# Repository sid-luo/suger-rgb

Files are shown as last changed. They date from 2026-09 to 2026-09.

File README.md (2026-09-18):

<p align="center">
  Suger RGB
</p>

<h1 align="center">Suger RGB</h1>

## ⚠️ DO NOT USE ESP32-C3 SUPER MINI — USE ESP32-C3 PRO MINI

> [!WARNING]
> **Do not buy or use an ESP32-C3 Super Mini (SuperMini) for this project.** These boards may have unreliable Wi-Fi, an undiscoverable setup hotspot, or failed Wi-Fi setup. A successful firmware flash does not guarantee working Wi-Fi.
>
> These issues occurred during this project's testing and were resolved by switching to an **ESP32-C3 Pro Mini**. **Choose the ESP32-C3 Pro Mini for this project.**

<p align="center">Turn Nightscout glucose and trend data into light you can understand at a glance.</p>

> [!TIP]
> ### ☁️ No Nightscout yet? Start in the cloud. Bring it to light.
>
> Try my other open-source project, [Nightscout for Cloudflare](https://github.com/sid-luo/nightscout-for-cloudflare): powered by Cloudflare, **ready to deploy in minutes**, and **completely free (no credit card required)**. **All your data stays under your control**, with no need to buy a server or configure MongoDB. Once it is set up, connect Suger RGB to bring your glucose levels and trends into the light around you.
>
> **[Explore the project →](https://github.com/sid-luo/nightscout-for-cloudflare)** · **[Deploy in your browser →](https://nscf.sidluo.com)**

<p align="center">
  <strong>English</strong> · <a href="README.zh-CN.md">简体中文</a>
</p>

<p align="center">
  <a href="https://rgb.sidluo.com/installer/"><strong>Web installer</strong></a>
  · <a href="https://rgb.sidluo.com/demo/"><strong>Effect demo</strong></a>
  · <a href="docs/GUIDE.en.md"><strong>Full guide</strong></a>
</p>

Suger RGB is an open-source glucose indicator built with an ESP32-C3 Pro Mini, WS2812B LEDs, and Nightscout. It reads the latest glucose value once per minute, uses color for the glucose range, and changes the light effect with the glucose trend.

This project aims to provide a low-cost way to help observe glucose trends. Search for `esp32-c3-mini-pro` and `ws2812b` on AliExpress, and you'll find plenty of affordable options. My skills are limited, and I don't currently have a 3D-printable model of my own. I only have one downloaded from [here](https://makerworld.com/zh/models/2008412-case-for-esp32-c3-pro-mini-esp32-c3fh4#profileId-2163305), which just about works for an LED strip. I'd appreciate support from more experienced makers.

When using a CGM, I often receive an alert only after my glucose has already gone high or low. After years of managing my glucose, I believe that seeing glucose trends “passively” is a very important part of the process. By the time I receive an alert from the CGM app, it may already be too late. Noticing changes in the light out of the corner of my eye can help me intervene earlier and try to avoid high or low glucose.

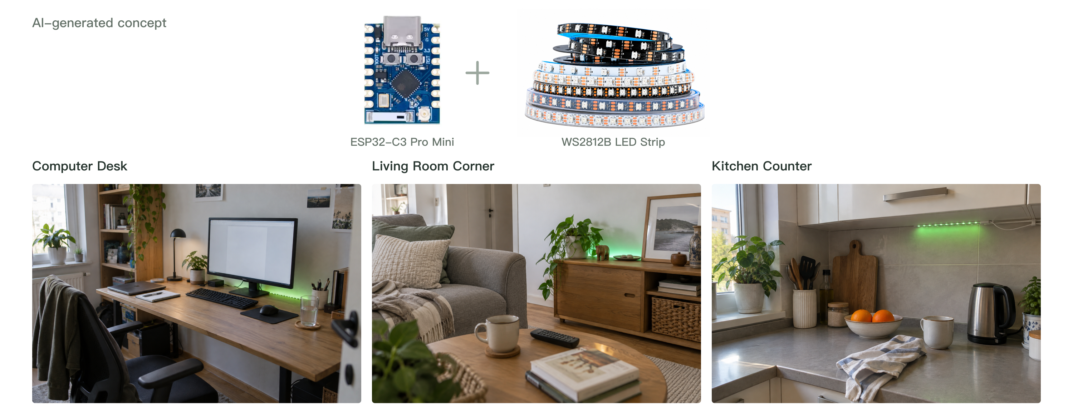
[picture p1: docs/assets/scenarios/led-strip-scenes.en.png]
LED strip scenes: computer desk, living room, and kitchen


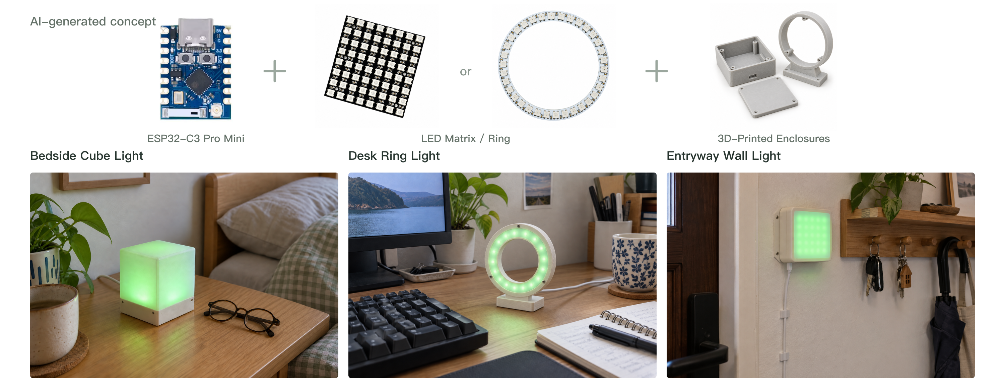
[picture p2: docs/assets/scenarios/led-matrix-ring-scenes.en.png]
LED matrix / ring and 3D-printed enclosure concepts


> [!IMPORTANT]
> Suger RGB is an open-source, community-based DIY project. It is not supported by any company and is not officially approved or regulated for diabetes therapy. You are responsible for building and running the device and use it at your own risk.

## What it shows

| mmol/L | mg/dL | Color |
| ---: | ---: | --- |
| `<3.5` | `<63` | Purple |
| `3.5–<4.4` | `63–79` | Blue |
| `4.4–<8.5` | `80–152` | Green |
| `8.5–<10` | `153–179` | Orange |
| `≥10` | `≥180` | Red |

The light effect changes with the Nightscout glucose trend. Open the [effect demo](https://rgb.sidluo.com/demo/) to see each glucose and arrow combination directly.

- A white breathing light appears when no valid new reading has arrived for 10 minutes
- The phone setup page supports Chinese, English, and live effect preview on the LEDs
- Works with 1–128 WS2812B pixels in a strip, ring, or panel

## What you need

### ⚠️ REMINDER: DO NOT BUY ESP32-C3 SUPER MINI

**Buy an ESP32-C3 Pro Mini. Super Mini boards may have Wi-Fi problems; do not use them for this project.**

| Part | Requirement |
| --- | --- |
| Controller | ESP32-C3 Pro Mini |
| LEDs | WS2812B strip, ring, or panel with 1–128 pixels |
| USB | A USB data cable and 5 V / 2 A power source |
| Network | 2.4 GHz Wi-Fi and an anonymously readable Nightscout site |

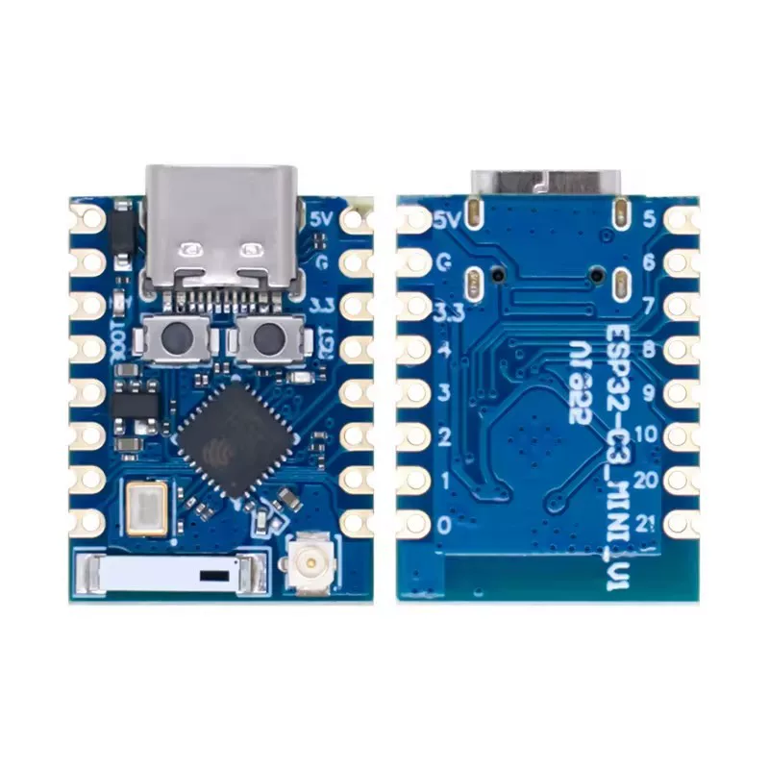
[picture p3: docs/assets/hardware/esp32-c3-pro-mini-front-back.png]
ESP32-C3 Pro Mini — front and back


Original board photo: front on the left, back on the right.

**Optional board enclosure**: [Original STL (body + lid)](docs/models/esp32-c3-pro-mini/Case_ESP32-C3_PRO_MINI_V01.stl) · [Body only](docs/models/esp32-c3-pro-mini/Case_ESP32-C3_PRO_MINI_V01_Body.stl) · [Lid only](docs/models/esp32-c3-pro-mini/Case_ESP32-C3_PRO_MINI_V01_Lid.stl). If your printing service does not accept the combined file, upload the body and lid separately. See the [model notes](docs/models/esp32-c3-pro-mini/README.en.md) for the designer, source, and license.

## Wiring

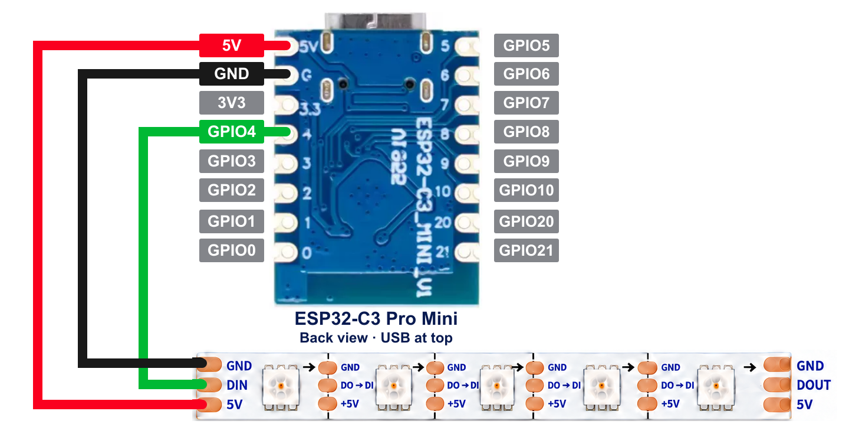
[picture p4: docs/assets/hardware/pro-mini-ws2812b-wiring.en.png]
ESP32-C3 Pro Mini GPIO4 to WS2812B DIN wiring


The wiring diagram shows the **back of the board with USB at the top**. Connect **5V → 5V, GND → GND, GPIO4 → DIN**. Follow the labels on your actual strip; pad order can vary.

```text
ESP32-C3 Pro Mini          WS2812B

5V    -------------------- 5V
GND   -------------------- GND
GPIO4 -------------------> DIN
```

Connect the data wire to `DIN`, not `DOUT`.

Board wiring close-up

## Get started

1. Connect the three wires above, then connect the ESP32-C3 Pro Mini over USB.
2. Open the [web installer](https://rgb.sidluo.com/installer/) in desktop Chrome or Edge and install the firmware.
3. Join the open `Suger-RGB-XXXX` Wi-Fi network on your phone.
4. Enter home Wi-Fi, the Nightscout address, and the LED count, then validate and save.
5. After restarting, the device reads Nightscout and displays the light automatically.

**Phone setup page**

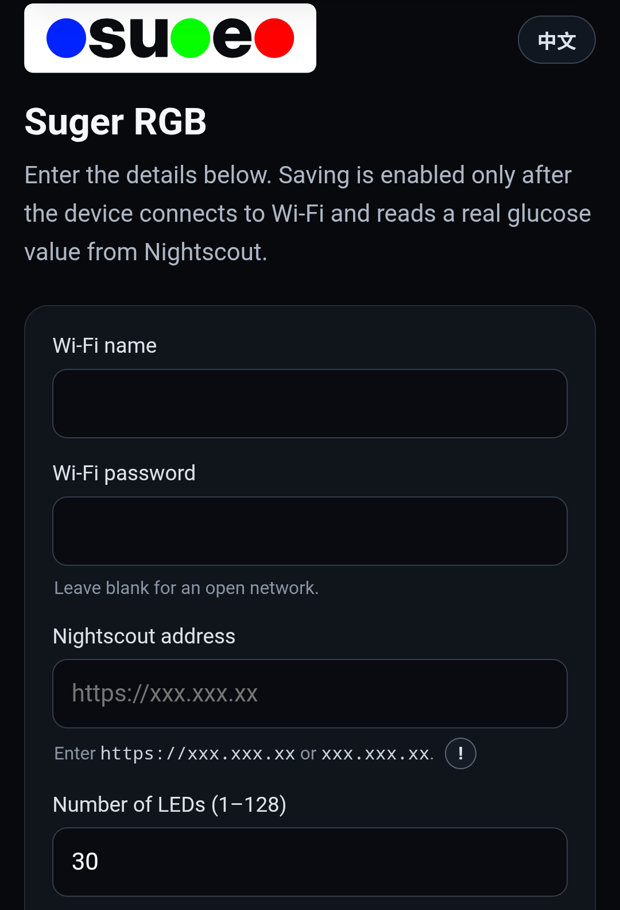
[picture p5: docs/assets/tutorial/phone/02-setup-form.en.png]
English setup page on a phone


To change the setup later, hold the board's BOOT button for about five seconds. See the [full user guide](docs/GUIDE.en.md) for every step and troubleshooting.

## Documentation

- [Full user guide](docs/GUIDE.en.md)
- [Interactive effect demo](https://rgb.sidluo.com/demo/)

## License and credits

Suger RGB is released under the [GNU GPL v3.0 or later](LICENSE). Some effects are adapted from MIT-licensed [WLED v0.14.4](https://github.com/wled/WLED/tree/v0.14.4). See [THIRD_PARTY_NOTICES.md](THIRD_PARTY_NOTICES.md) for complete source and copyright notices.

The board enclosure model is by Mattia Carli. The original and split STL files are separately licensed under [CC BY-NC-SA 4.0](https://creativecommons.org/licenses/by-nc-sa/4.0/).

Thanks to the [Nightscout](https://nightscout.github.io/) community, the WLED project, and every open-source contributor.

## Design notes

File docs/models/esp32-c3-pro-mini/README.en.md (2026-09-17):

# ESP32-C3 Pro Mini board enclosure

[简体中文](README.md) · [Back to the full guide](../../GUIDE.en.md)

The original model is by **[Mattia Carli](https://makerworld.com/zh/@MattiaCarli)**: [Case for ESP32-C3 PRO MINI ESP32-C3FH4 on MakerWorld](https://makerworld.com/zh/models/2008412-case-for-esp32-c3-pro-mini-esp32-c3fh4#profileId-2163305). This enclosure holds the controller board; it is not one of the complete lamp housings shown in the project's AI concept images.

## Downloads

| File | Contents | When to use it |
| --- | --- | --- |
| [Original STL](Case_ESP32-C3_PRO_MINI_V01.stl) | Body and lid in one file | Your slicer or printing service supports two separate parts in one file |
| [Body STL](Case_ESP32-C3_PRO_MINI_V01_Body.stl) | Body only | Upload and print each part separately |
| [Lid STL](Case_ESP32-C3_PRO_MINI_V01_Lid.stl) | Lid only | Print together with the body |

If a printing service does not accept two separate parts in a single file, upload the **body** and **lid** separately. Print one of each. The combined file was not accepted when this project used JLC's printing service, which is why the split files are provided.

## Changes in the split files

The Suger RGB maintainer separated the original model into two files and repositioned each part so it is centered on X/Y with its base at Z=0. The parts were not scaled and the enclosure geometry was not redesigned. The original file was renamed for consistency; its contents are unchanged.

| Part | Outside dimensions when imported in millimeters |
| --- | --- |
| Body | Approximately 29.30 × 21.70 × 7.50 mm |
| Lid | Approximately 29.30 × 21.70 × 3.30 mm |

STL files do not store units, so check these dimensions when importing. Both split parts are positioned near their own origin. If importing them together, arrange them as separate objects to avoid overlap. Check your board's dimensions and connector positions before printing; geometry checks do not verify the printed fit.

## Attribution and license

Original designer: Mattia Carli. The original model and the split files in this directory are licensed under **[CC BY-NC-SA 4.0](https://creativecommons.org/licenses/by-nc-sa/4.0/)** (Attribution–NonCommercial–ShareAlike), rather than the project's software GPL license. Retain the designer credit, source link, license, and description of changes when sharing these files.

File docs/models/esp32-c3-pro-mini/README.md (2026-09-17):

# ESP32-C3 Pro Mini 主板保护壳

[English](README.en.md) · [返回详细教程](../../GUIDE.md)

原模型由 **[Mattia Carli](https://makerworld.com/zh/@MattiaCarli)** 制作，来源为 MakerWorld 的 [Case for ESP32-C3 PRO MINI ESP32-C3FH4](https://makerworld.com/zh/models/2008412-case-for-esp32-c3-pro-mini-esp32-c3fh4#profileId-2163305)。这是主板保护壳，不是项目首页 AI 效果图中的完整灯具外壳。

## 文件下载

| 文件 | 内容 | 适用情况 |
| --- | --- | --- |
| [原版 STL](Case_ESP32-C3_PRO_MINI_V01.stl) | 盒体和盖子位于同一个文件中 | 切片软件或打印平台支持在同一文件中处理两个零件 |
| [盒体 STL](Case_ESP32-C3_PRO_MINI_V01_Body.stl) | 单独的盒体 | 分别上传、打印两个零件 |
| [盖子 STL](Case_ESP32-C3_PRO_MINI_V01_Lid.stl) | 单独的盖子 | 与盒体配套使用 |

如果打印平台不接受一个文件中包含两个独立零件，请分别上传**盒体**和**盖子**，两件都需要打印。本项目在嘉立创上传组合文件时遇到不接受的情况，因此提供拆分版。

## 拆分说明

拆分版由 Suger RGB 项目维护者提供：只把原模型中的两个零件分到独立文件，并将各自的位置移到 X/Y 居中、底部 Z=0；没有缩放或修改外壳结构。原版文件仅统一了文件名，内容保持不变。

| 零件 | 外部尺寸（按毫米导入时） |
| --- | --- |
| 盒体 | 约 29.30 × 21.70 × 7.50 mm |
| 盖子 | 约 29.30 × 21.70 × 3.30 mm |

STL 本身不记录单位，导入时请核对上述尺寸。两个拆分文件都位于各自原点附近，同时导入切片软件时应作为独立对象排列，避免重叠。打印前请核对自己的主板尺寸和接口位置；文件几何检查不等于实际打印、装配验证。

## 作者与许可

原作者：Mattia Carli。原模型及本目录拆分文件遵循 **[CC BY-NC-SA 4.0](https://creativecommons.org/licenses/by-nc-sa/4.0/)**（署名—非商业性使用—相同方式共享），不适用项目软件的 GPL 许可。分享这些文件时，请保留作者、来源、许可和拆分说明。

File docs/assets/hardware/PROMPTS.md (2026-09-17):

# Hardware artwork sources

The board front/back photograph and pinout diagram were supplied by the user and are retained unchanged. The strip product reference was also supplied by the user and copied unchanged.

## Current wiring diagrams

`pro-mini-ws2812b-wiring.svg` and `pro-mini-ws2812b-wiring.en.svg` are editable compositions; the corresponding PNG files are rendered from those SVG files. Each SVG embeds the original board photograph without changing its image bytes, clips to the back view, and scales it uniformly by 1.1. Pin labels and right-angle wire paths are separate vector elements.

The strip illustration was generated with image_gen and corrected against the supplied strip reference. The input pads are GND, DIN, 5V from top to bottom; each gap between adjacent LEDs contains three solder pads. Black connects GND to GND, green connects GPIO4 to DIN, and red connects 5V to 5V. The crossing wires have no junction.

The Chinese caption is “背面 · USB 朝上”; the English caption is “Back view · USB at top”. Standalone USB power annotations, the large data-direction arrow/caption, and the footer were removed at the user's request. Printed arrows on the strip remain.

### Final strip and wire geometry prompt

Keep five LEDs and three copper solder pads with a cut line between every adjacent pair. All strip pad stacks are top GND, middle data, bottom +5V. The input data pad is DIN; the output is DOUT; internal data joints are DO → DI. Arrows point right. Draw three independent unbranched wires with horizontal and vertical segments and square 90-degree turns: board 5V to bottom strip 5V in red, board GND to top strip GND in black, board GPIO4 to middle strip DIN in green. Black may cross over green without a junction dot. Preserve the original motherboard photo; do not regenerate its traces, pads, proportions, or silkscreen.

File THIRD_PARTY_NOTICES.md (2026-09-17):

# Third-party notices

## ESP32-C3 Pro Mini enclosure

The three STL files in `docs/models/esp32-c3-pro-mini/` are based on **Case for ESP32-C3 PRO MINI ESP32-C3FH4** by [Mattia Carli](https://makerworld.com/zh/@MattiaCarli).

Source: [MakerWorld model 2008412, print profile 2163305](https://makerworld.com/zh/models/2008412-case-for-esp32-c3-pro-mini-esp32-c3fh4#profileId-2163305)

License: [Creative Commons Attribution–NonCommercial–ShareAlike 4.0 International (CC BY-NC-SA 4.0)](https://creativecommons.org/licenses/by-nc-sa/4.0/). This license applies to the enclosure models independently of the project's software GPL license.

- `Case_ESP32-C3_PRO_MINI_V01.stl`: original combined body and lid, renamed without changing file contents.
- `Case_ESP32-C3_PRO_MINI_V01_Body.stl` and `Case_ESP32-C3_PRO_MINI_V01_Lid.stl`: separated by the Suger RGB maintainer and repositioned so each part is centered on X/Y with its base at Z=0. No scaling or enclosure geometry changes.

The split files are shared under the same CC BY-NC-SA 4.0 license. Retain attribution, the source and license links, and the description of changes when redistributing these models.

## Inter typeface

The `su` and `e` vector outlines in the Suger RGB logo are derived from Inter ExtraBold with optical size 32 and weight 800. The firmware does not ship the complete font binary.

Source: <https://github.com/google/fonts/tree/main/ofl/inter>

Upstream project: <https://github.com/rsms/inter>

```text
Copyright 2020 The Inter Project Authors (https://github.com/rsms/inter)
```

Inter is provided under the SIL Open Font License, Version 1.1. See [`licenses/Inter-OFL-1.1.txt`](licenses/Inter-OFL-1.1.txt).

## WLED v0.14.4 effects

Parts of `main/led_controller.c` are modified, standalone adaptations of the following effects and helpers from WLED v0.14.4:

- Fade / triangular luminance envelope
- Color Twinkles
- Twinklefox
- Chase Rainbow
- Theater Chase Rainbow

Source: <https://github.com/wled/WLED/blob/v0.14.4/wled00/FX.cpp>

Pinned release license: <https://github.com/wled/WLED/blob/v0.14.4/LICENSE>

The code was modified in 2026 for a small ESP-IDF C firmware, fixed glucose colors, a non-zero low-brightness floor, a bounded LED count, and a project-wide output-current budget. It is not a copy of or replacement for the complete WLED firmware.

The notices associated with the upstream source include:

```text
Copyright (c) 2016 Harm Aldick
Copyright (c) 2016 Christian Schwinne
```

WLED v0.14.4 and the relevant upstream effect source are provided under the MIT License:

```text
MIT License

Permission is hereby granted, free of charge, to any person obtaining a copy
of this software and associated documentation files (the "Software"), to deal
in the Software without restriction, including without limitation the rights
to use, copy, modify, merge, publish, distribute, sublicense, and/or sell
copies of the Software, and to permit persons to whom the Software is
furnished to do so, subject to the following conditions:

The above copyright notice and this permission notice shall be included in all
copies or substantial portions of the Software.

THE SOFTWARE IS PROVIDED "AS IS", WITHOUT WARRANTY OF ANY KIND, EXPRESS OR
IMPLIED, INCLUDING BUT NOT LIMITED TO THE WARRANTIES OF MERCHANTABILITY,
FITNESS FOR A PARTICULAR PURPOSE AND NONINFRINGEMENT. IN NO EVENT SHALL THE
AUTHORS OR COPYRIGHT HOLDERS BE LIABLE FOR ANY CLAIM, DAMAGES OR OTHER
LIABILITY, WHETHER IN AN ACTION OF CONTRACT, TORT OR OTHERWISE, ARISING FROM,
OUT OF OR IN CONNECTION WITH THE SOFTWARE OR THE USE OR OTHER DEALINGS IN THE
SOFTWARE.
```

The current WLED main branch uses a different license. Suger RGB intentionally references the historical v0.14.4 tag above; do not replace the source link with `main` without reviewing the licensing impact.

## ESP Web Tools 10.4.0

The browser installer bundles the `dist/web` build of ESP Web Tools 10.4.0.

Source: <https://github.com/esphome/esp-web-tools/tree/10.4.0>

ESP Web Tools is provided under the Apache License 2.0. The bundled license is at [`docs/installer/vendor/esp-web-tools/LICENSE`](docs/installer/vendor/esp-web-tools/LICENSE).

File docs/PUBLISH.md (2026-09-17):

# 发布 Suger RGB

本文面向项目维护者。普通用户请阅读 [`INSTALL.md`](INSTALL.md)。

## 1. 准备版本

1. 更新根目录 `VERSION`；
2. 同步更新 `CHANGELOG.md`；
3. 同步更新 `docs/installer/manifest.json` 中的 `version`；
4. 在 ESP-IDF 5.4.x 环境执行：

```bash
./tools/package_web_firmware.sh
```

5. 完成 [`RELEASE_CHECKLIST.md`](RELEASE_CHECKLIST.md)。

## 2. 网站入口与部署

当前正式入口为：

- 网页安装器：<https://rgb.sidluo.com/installer/>
- 灯效演示：<https://rgb.sidluo.com/demo/>

更新网站时，将整个 `docs/` 目录部署到网站托管服务，保持目录结构不变。

如需另外启用 GitHub Pages，仓库上传至 `sid-luo/suger-rgb` 后：

1. 打开仓库 `Settings`；
2. 进入 `Pages`；
3. 在 `Build and deployment` 中选择 `Deploy from a branch`；
4. 选择 `main` 分支和 `/docs` 目录；
5. 保存并等待部署完成。

`docs/.nojekyll` 必须保留。安装页、ESP Web Tools、清单和固件都位于 `/docs`，因此不依赖第三方 CDN。

## 3. 创建 GitHub Release

建议为每个版本附带：

- `suger-rgb-esp32c3.bin`；
- `SHA256SUMS.txt`；
- 该版本对应的源代码；
- 从 `CHANGELOG.md` 摘取的更新说明。

网页安装器使用的合并固件会清除旧配置。发布说明中应明确提示用户刷写后重新配网。

## 4. 国内镜像

将整个 `docs/` 目录原样部署至支持 HTTPS 的国内静态网站托管即可。不要只复制 `index.html`，以下内容必须保持相对目录不变：

```text
installer/manifest.json
installer/firmware/
installer/vendor/esp-web-tools/
installer/assets/
demo/
```

部署后分别检查中文、英文、灯效演示、固件下载响应和 SHA-256。镜像与正式站应使用同一个发布版本，不单独修改固件。

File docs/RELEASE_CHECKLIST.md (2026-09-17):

# Suger RGB 发布检查清单

## 版本与构建

- [ ] `VERSION`、`CHANGELOG.md` 与 `docs/installer/manifest.json` 版本一致；
- [ ] 使用干净的 ESP-IDF 5.4.x 环境执行 `idf.py build`；
- [ ] 执行 `./tools/package_web_firmware.sh`；
- [ ] 合并固件通过 `esptool image_info`；
- [ ] `SHA256SUMS.txt` 与实际文件一致。

## 首次安装

- [ ] 从未知固件开始，网页安装并选择清除设备；
- [ ] 安装器拒绝非 ESP32-C3 芯片；
- [ ] 首次启动显示低亮度白光追逐；
- [ ] `Suger-RGB-XXXX` 为无密码热点；
- [ ] Captive Portal 与 `http://192.168.4.1/` 均可打开；
- [ ] 中英文切换、Nightscout 验证、保存和重启正常。

## 正常运行与实体权限

- [ ] 保存后设备只连接家庭 Wi-Fi，不保留 AP；
- [ ] 正常运行的局域网 IP 没有 HTTP 设置页面；
- [ ] 长按 BOOT 约 5 秒后才开放配网页；
- [ ] 配网状态下再次独立长按约 5 秒，三次白光反馈后清除连接配置；
- [ ] 强制恢复保留灯珠数量。

## 数据与灯效

- [ ] Nightscout URL 自动补全和匿名读取正常；
- [ ] 五档颜色与 README 表格一致；
- [ ] `↑ ⇈ ↓ ⇊` 四种动态趋势与设置页预览一致；
- [ ] `<3.3 mmol/L` 与 `≥15 mmol/L` 优先级正确且不可关闭；
- [ ] 10 分钟无新数据进入白光呼吸。

## 发布

- [ ] GitHub Pages 安装页通过 HTTPS 加载；
- [ ] 安装页不依赖第三方 CDN；
- [ ] 灯效演示可自动轮播，并能手动切换血糖、趋势和三种灯珠布局；
- [ ] 灯效演示的中英文、颜色区间和固件自动映射一致；
- [ ] GitHub Release 附带合并固件和 SHA-256；
- [ ] 国内镜像使用相同固件并核对 SHA-256；
- [ ] README、英文 README、许可和第三方声明均为当前版本。

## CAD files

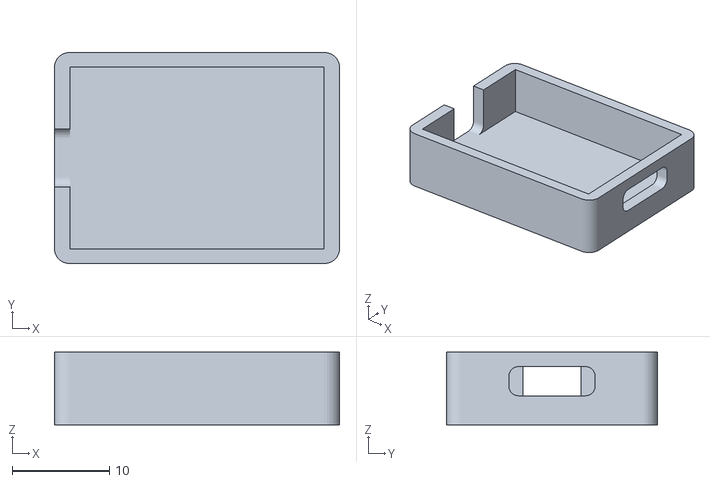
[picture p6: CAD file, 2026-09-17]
docs/models/esp32-c3-pro-mini/Case_ESP32-C3_PRO_MINI_V01_Body.stl
29.3 x 21.7 x 7.50

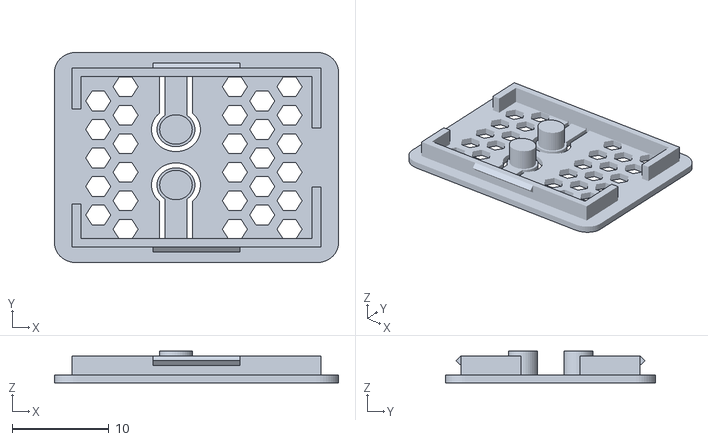
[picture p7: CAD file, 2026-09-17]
docs/models/esp32-c3-pro-mini/Case_ESP32-C3_PRO_MINI_V01_Lid.stl
29.3 x 21.7 x 3.30

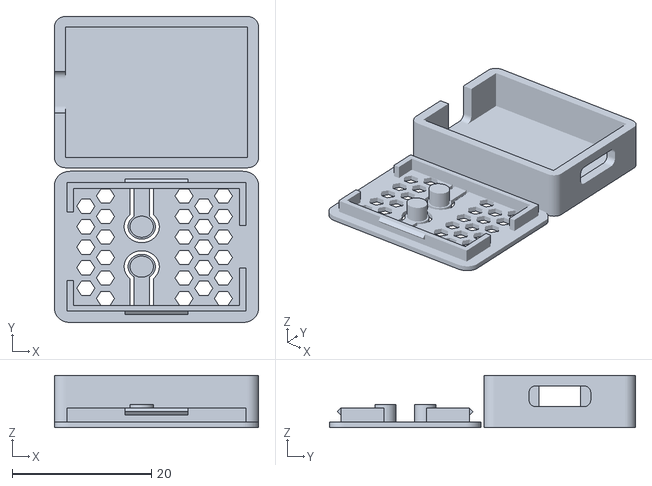
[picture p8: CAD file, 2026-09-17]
docs/models/esp32-c3-pro-mini/Case_ESP32-C3_PRO_MINI_V01.stl
29.3 x 43.9 x 7.50

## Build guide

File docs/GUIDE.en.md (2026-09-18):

# Suger RGB User Guide

[简体中文](GUIDE.md) · [Project home](../README.md) · [Web installer](https://rgb.sidluo.com/installer/)

For your first build, follow this order: **gather the parts → connect the wires → flash from a computer → set up from a phone → place the device where you want to use it.** You do not need a development environment or any code changes.

If your device is already working and you only want to change Wi-Fi or other settings, go to [Change settings](#change-settings). For help with a problem, see [Troubleshooting](#troubleshooting).

## ⚠️ DO NOT USE ESP32-C3 SUPER MINI — USE ESP32-C3 PRO MINI

> [!WARNING]
> **Do not buy or use an ESP32-C3 Super Mini (SuperMini) for this project.** During this project's testing, these boards had problems such as a missing setup hotspot and unstable Wi-Fi. Switching to an **ESP32-C3 Pro Mini** resolved them. A successful firmware flash does not establish that the wireless connection works correctly.

> [!IMPORTANT]
> Suger RGB is a community DIY project that turns existing CGM data into light. It cannot replace the original CGM readings, alarms, medical judgment, or treatment advice. You are responsible for building and using the device.

## 1. Gather the parts

| What you need | Requirements |
| --- | --- |
| Controller | **ESP32-C3 Pro Mini with 4 MB flash** |
| LEDs | A **5 V WS2812B** strip, ring, or matrix with 1–128 LEDs |
| Wiring materials | Three wires for 5V, GND, and data input; soldering or connection materials appropriate for your board and LEDs |
| USB data cable | Must carry data, not just power |
| Computer | For browser flashing; desktop Chrome or Edge is recommended |
| Phone | To join the device's hotspot and enter settings |
| Power source for everyday use | USB 5 V / 2 A power supply |
| Home network | A 2.4 GHz Wi-Fi network that can reach Nightscout |
| Nightscout | An HTTPS site receiving glucose data and allowing anonymous access to that data |

Search for `esp32-c3-mini-pro` and `ws2812b` on AliExpress to find the parts. **Check again that you are buying a Pro Mini, not a Super Mini.**

If you do not have Nightscout yet, take a look at [Nightscout for Cloudflare](https://github.com/sid-luo/nightscout-for-cloudflare#rgb). The current firmware has no API_SECRET or Token field, so it cannot read data from a site that requires a secret or token.

You can add an enclosure after the device is working. Count the LEDs first, and use your phone's normal Internet connection to check that Nightscout is receiving new data.

ESP32-C3 Pro Mini front and back

The front is on the left and the back is on the right. The wiring diagram below shows the **back of the board, with the USB connector at the top**.

## 2. Connect the three wires

**Disconnect USB and any other power source before wiring.**

ESP32-C3 Pro Mini to WS2812B strip wiring

| Board pin | Connect to the LEDs | Purpose |
| --- | --- | --- |
| `5V` | `5V` or `+5V` | Positive power connection |
| `GND` | `GND` or `G` | Common ground |
| `GPIO4` (marked `4` on the board) | `DIN` or `DI` | Data input |

The arrows on a strip show the direction of data flow: data enters `DIN` from the controller, then passes to the following LEDs. `DOUT` or `DO` is the output and cannot be used as the input. **Pad positions can vary. Follow the printed labels on your actual LEDs, rather than assuming a connection belongs at the top or bottom.**

Rings and matrices use the same three connections. Check for loose connections and solder bridging adjacent pads, then connect the board to your computer with a USB data cable.

<details>
<summary>View the complete pinout and LED strip reference photo</summary>

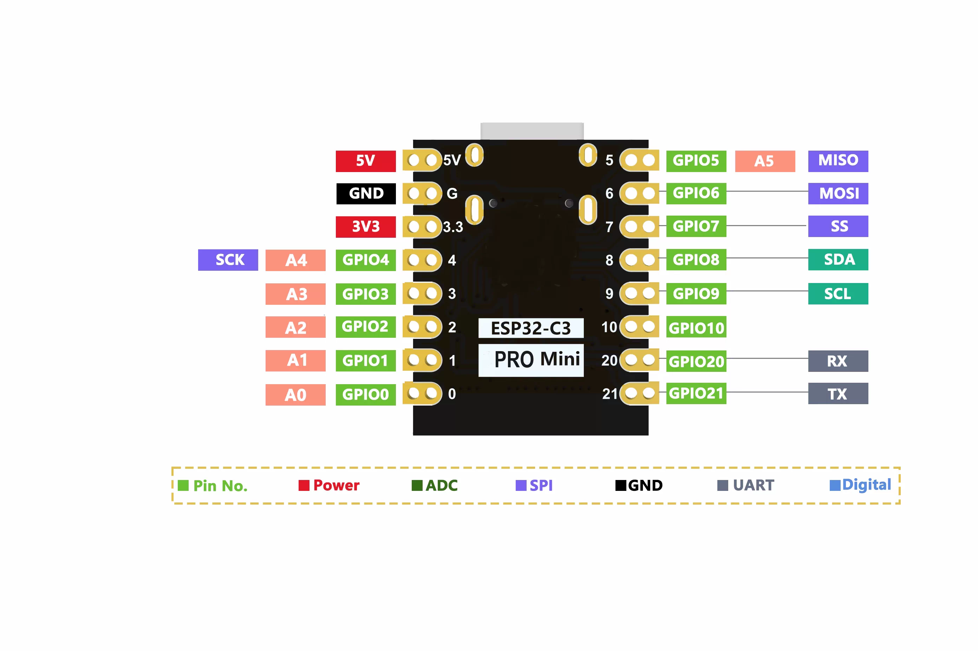
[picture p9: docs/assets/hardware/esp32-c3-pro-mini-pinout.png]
ESP32-C3 Pro Mini pinout, viewed from the back


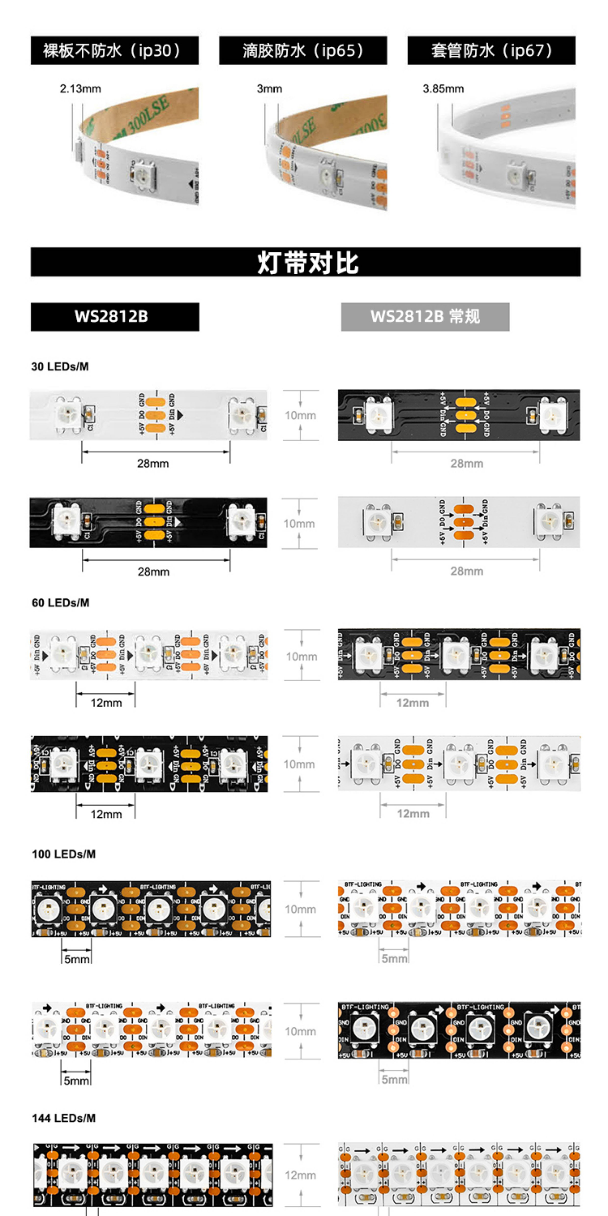
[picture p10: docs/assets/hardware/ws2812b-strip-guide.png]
WS2812B strip reference photo, with solder pads between adjacent LEDs


</details>

### Wiring photos

**Board wiring close-up**

Board wiring close-up

**Board and cable**

Board and cable

**Board and LED strip assembly**

Board and LED strip assembly

## 3. Flash the firmware from a computer

Open the [Suger RGB web installer](https://rgb.sidluo.com/installer/) in Chrome or Edge on your computer.

### 3.1 Open the installer

Connect your **ESP32-C3 Pro Mini** using a USB **data cable**, then click **Connect and install**.

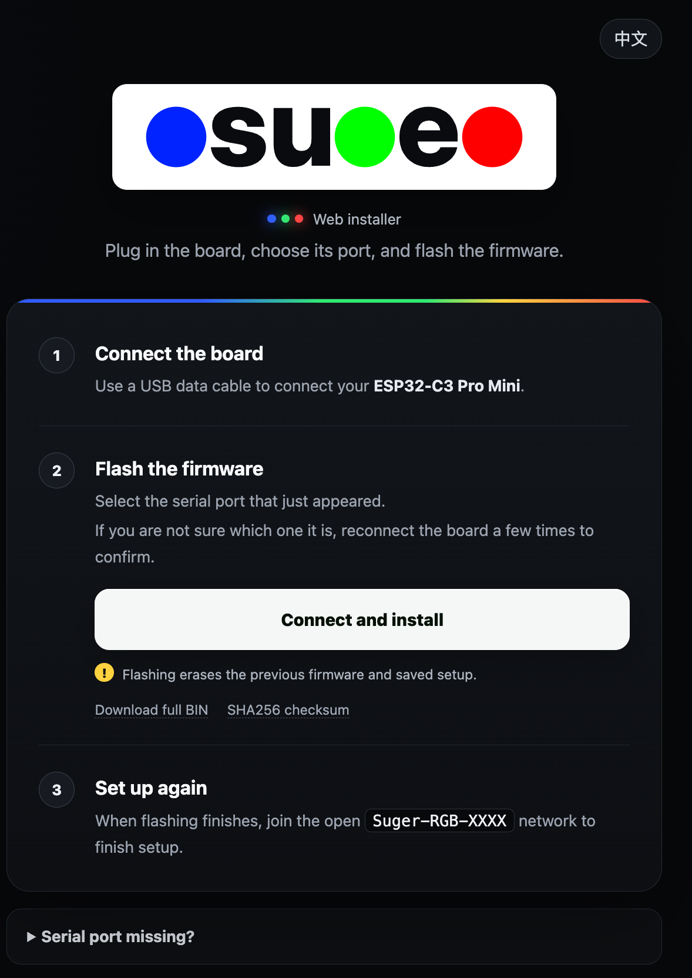
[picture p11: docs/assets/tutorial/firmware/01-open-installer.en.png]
Web installer showing the Connect and install button


### 3.2 Identify the board's serial port

If several ports are listed, use this comparison **before starting installation**:

1. Unplug the board and check the list.
2. Reconnect it and look for the entry that appears again. If the list does not refresh, cancel the dialog and click **Connect and install** again.
3. Select that entry, then click **Connect**.

| Board unplugged | Board reconnected |
| --- | --- |
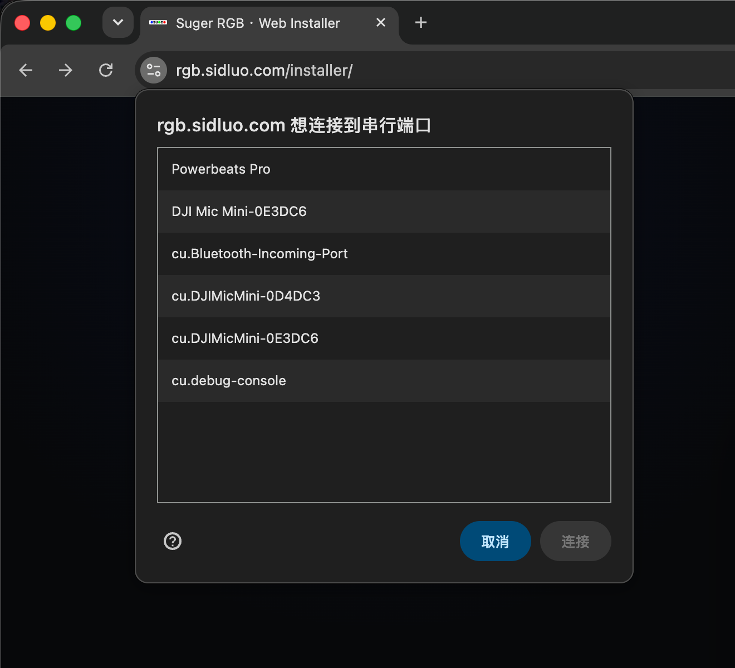
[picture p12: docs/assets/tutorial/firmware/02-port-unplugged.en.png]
Board unplugged: the USB JTAG serial port is absent
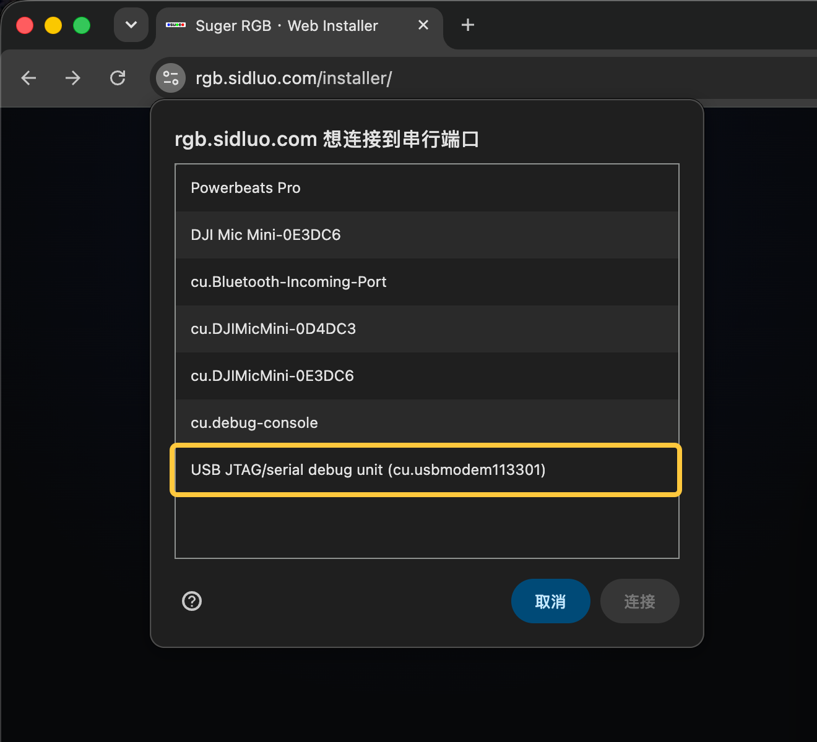
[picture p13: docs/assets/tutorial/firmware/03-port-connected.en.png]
Board reconnected: a USB JTAG serial port appears
|  |  |
| No entry for the board. | A new **USB JTAG/serial debug unit** entry appears. |

In these macOS screenshots, the port is `USB JTAG/serial debug unit (cu.usbmodem113301)`. Its name and number may differ on your computer; identify it by unplugging and reconnecting the board, rather than matching this number.

The browser's port-selection dialog is shown in Chinese here: **连接 = Connect**, **取消 = Cancel**. Its language follows the browser, so switching the installer page to English may not change this dialog.

### 3.3 Choose Install Suger RGB

Once the board is connected, click **Install Suger RGB** in the menu.

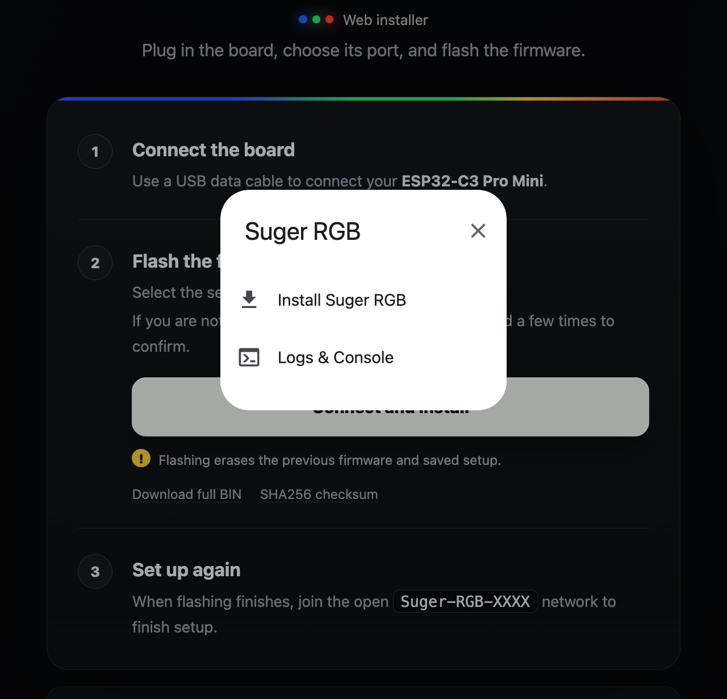
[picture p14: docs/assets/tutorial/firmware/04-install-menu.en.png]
Connected-device menu with Install Suger RGB


### 3.4 Confirm installation

Click **Install** in the confirmation dialog. **This erases the previous firmware and saved setup information.**

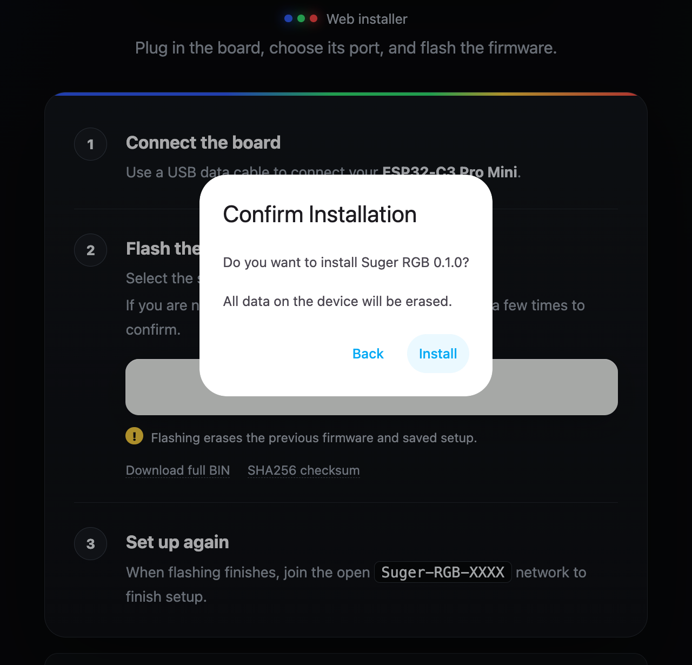
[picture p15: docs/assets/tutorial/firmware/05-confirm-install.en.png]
Confirm Installation dialog with the Install button


### 3.5 Wait for the firmware to be written

Keep the page visible and the USB cable connected while the progress indicator runs. Wait until the installer reports completion.

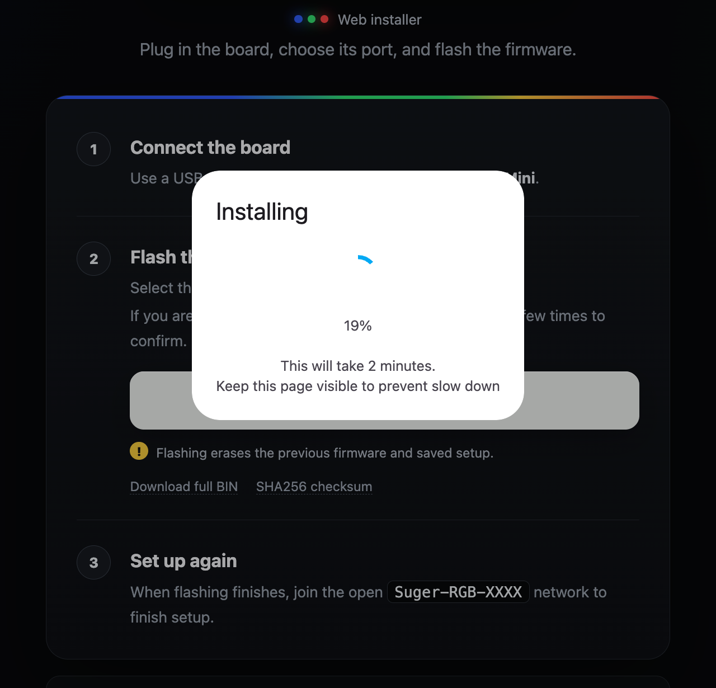
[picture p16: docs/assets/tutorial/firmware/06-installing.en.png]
Installing dialog showing firmware write progress


### 3.6 Check that installation is complete

When **Installation complete!** appears, click **Next** and allow the board to restart.

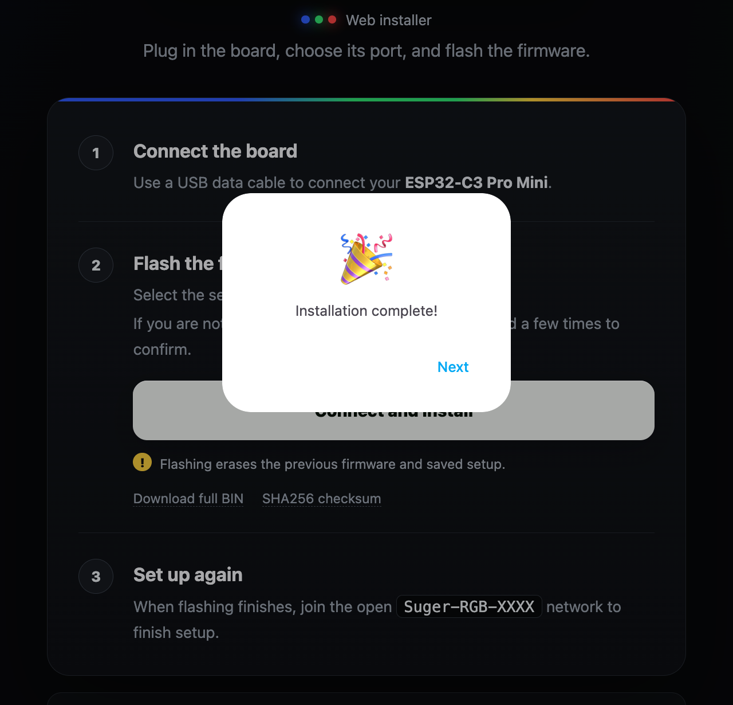
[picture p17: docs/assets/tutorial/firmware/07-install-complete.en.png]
Installation complete message and Next button


The board then enters setup mode. With the LEDs wired correctly, they show a dim white chase. Continue with [phone Wi-Fi setup](#4-set-up-the-device-from-your-phone) and look for the open `Suger-RGB-XXXX` network.

If the serial port cannot be opened, see [Serial port will not open](#serial-port-will-not-open).

## 4. Set up the device from your phone

### Join the device's hotspot

A device without complete saved setup information enters setup mode automatically on startup. If it has already been configured, first [hold BOOT to enter setup mode](#change-settings).

1. Open your phone's Wi-Fi settings and join **`Suger-RGB-XXXX`**. The final characters vary by device. The hotspot has no password.
2. If your phone warns that the network has no Internet connection, choose to stay connected. Your phone is connecting directly to the lamp's setup page.
3. Wait for the setup page to appear. If it does not open automatically, stay connected to the hotspot and enter **`http://192.168.4.1/`** in your browser's address bar.

The device hotspot is available in the Wi-Fi list below. Tap **`Suger-RGB-XXXX`** to connect.

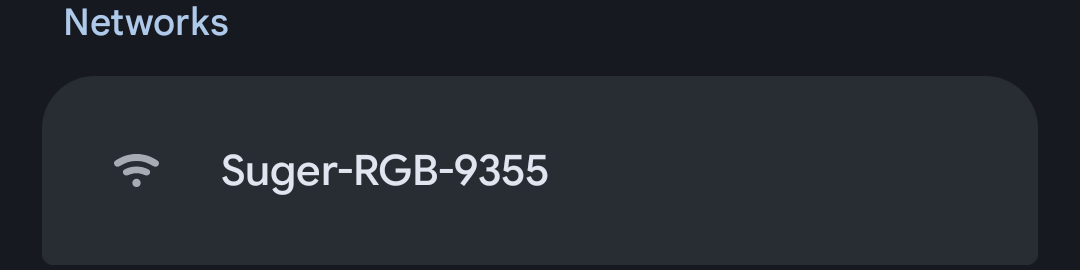
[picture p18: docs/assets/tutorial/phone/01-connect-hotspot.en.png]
Phone Wi-Fi list showing the available Suger-RGB-XXXX device hotspot


### Enter the settings

Use the button at the top right of the setup page to switch between Chinese and English.

English setup page with Wi-Fi, Nightscout address, and LED count fields

| Field or option | What to enter or choose |
| --- | --- |
| Wi-Fi name | The name of your home **2.4 GHz Wi-Fi** network, not `Suger-RGB-XXXX` |
| Wi-Fi password | The password for that home network; leave blank for an open network |
| Nightscout address | For example, `https://example.com`; `example.com` also works |
| Number of LEDs (1–128) | The total number of connected LEDs; for example, enter `64` for an 8×8 matrix |
| Dynamic trend alerts | On by default; when off, the ordinary glucose ranges use a steady color |

You do not need to add the Nightscout API path yourself. The device adds it automatically. The current firmware supports HTTPS only.

The dynamic trend switch does not disable the special effects for very low or very high glucose. See [What the lights mean](#5-what-the-lights-mean).

### Test the light effects

Tap **the `!` next to “Dynamic trend alerts”** to expand the test panel. Tap a low/high glucose card or a trend arrow to preview its effect on the LEDs. Tap `!` again to close the panel and stop the preview.

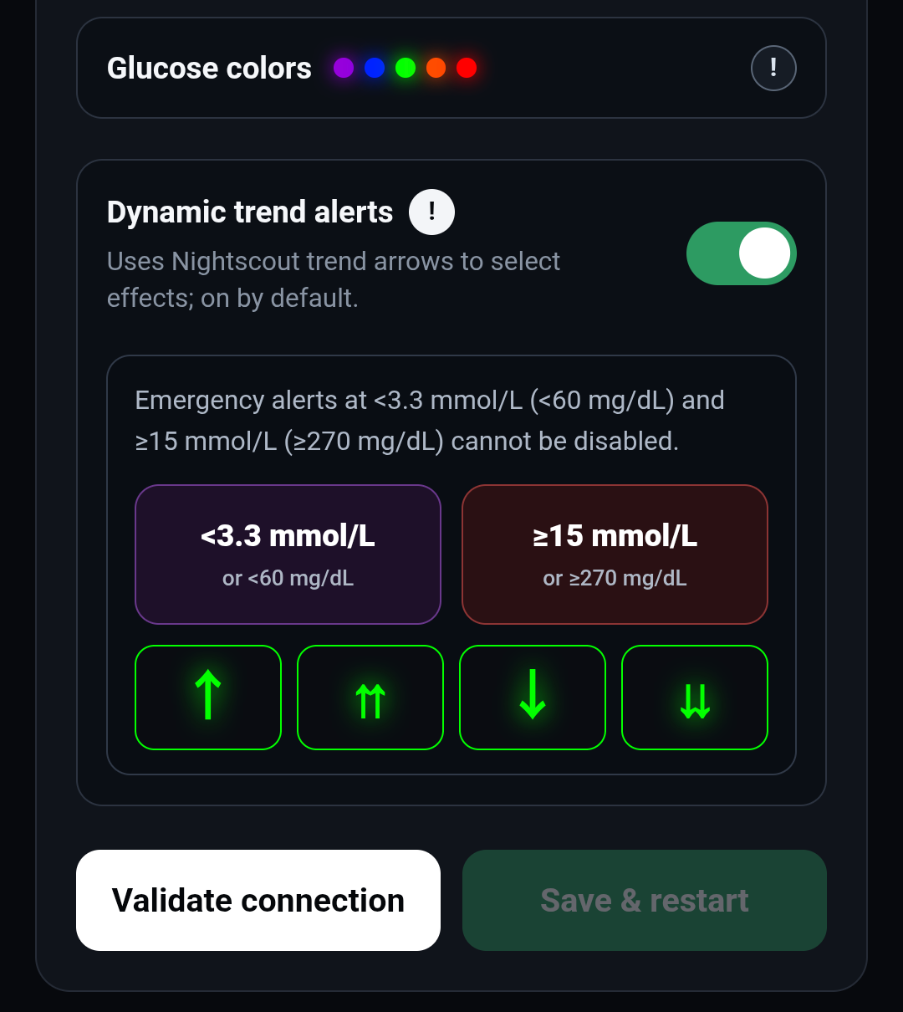
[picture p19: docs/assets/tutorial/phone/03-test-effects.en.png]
Expanded dynamic trend panel with low and high glucose cards and trend arrows for testing the LEDs


Testing previews the light effects only; it does not change glucose records in Nightscout.

### Validate and save

1. Select **“Validate connection”**. The device tries to connect to your home Wi-Fi and requests glucose data from Nightscout.
2. After validation succeeds, the page shows the glucose reading, data age, and trend. Check that these are what you expect.

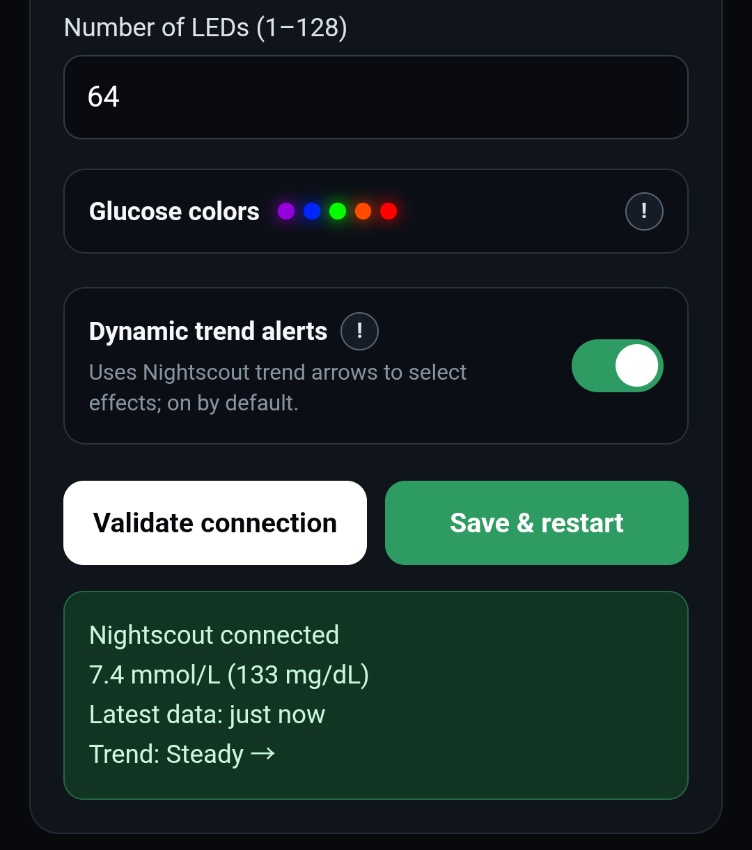
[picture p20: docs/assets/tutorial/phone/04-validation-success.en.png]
Nightscout connected, with glucose and trend data and the Save & restart button enabled


3. Select **“Save & restart”**. Validation alone does not save the setup.
4. Wait for the device to restart. Your phone can return to its usual Wi-Fi network.

**What you should see:** the device connects to your home Wi-Fi and shows the glucose color and trend effect after reading valid data. The setup hotspot and page close during normal operation.

If the page reports that the data is more than 10 minutes old, the LEDs will show a white breathing effect even if you can save. Check that Nightscout is receiving new data first.

## 5. What the lights mean

The device reads Nightscout about once per minute. The lights reflect records that Nightscout has already received, so delays in CGM uploads or the network also affect the display.

### Glucose colors

| mmol/L | mg/dL | Color |
| ---: | ---: | --- |
| `<3.5` | `<63` | Purple |
| `3.5–<4.4` | `63–79` | Blue |
| `4.4–<8.5` | `80–152` | Green |
| `8.5–<10` | `153–179` | Orange |
| `≥10` | `≥180` | Red |

### Trend effects

With “Dynamic trend alerts” enabled, the ordinary glucose ranges use these effects:

| Nightscout trend | Light effect |
| --- | --- |
| `↑` Rising | Gentle breathing in the current glucose color |
| `⇈` Rising quickly | Faster breathing |
| `↓` Falling | Reverse gradual fill |
| `⇊` Falling quickly | Reverse comet |
| `→`, `↗`, `↘`, or another trend | Steady light in the current glucose color |

### Special displays

| State | Light effect |
| --- | --- |
| Glucose below `60 mg/dL` (about `3.3 mmol/L`) | Purple double pulse, overriding ordinary trend effects |
| Glucose at or above `270 mg/dL` (`15 mmol/L`) | Multicolor twinkling (Twinklefox), overriding ordinary trend effects |
| Just started and has not read data yet, or the data has expired | White breathing |
| Setup mode | Dim white chase |
| Clearing connection information | Three slow white pulses |

The special effects for very low and very high glucose remain enabled even when dynamic trend alerts are off. White breathing is not a glucose range color; during normal operation, data that has not been updated for more than 10 minutes triggers this state.

After saving the settings, you can disconnect the computer and use your everyday USB power source. Removing power does not clear the settings. On the next startup, the device reconnects to the saved home Wi-Fi network.

## 6. Change settings or set up again

### Change settings

To change your home Wi-Fi, Nightscout address, LED count, or dynamic trend setting:

1. Power the device normally.
2. Hold the board's **BOOT button for about five seconds**, then release it when you see the white chase.
3. Join `Suger-RGB-XXXX` on your phone and open the setup page or `http://192.168.4.1/`.
4. Change the settings, select **“Validate connection”** again, then **“Save & restart”**.

If the Wi-Fi name is unchanged, leaving the password field blank keeps the saved password. When switching to a different password-protected network, enter its password.

During normal operation, the device's IP address on your home network does not provide a settings page. Use the physical BOOT button to enter setup mode first.

### Clear saved connection information

Use these steps only when you want to clear the home Wi-Fi and Nightscout address:

1. Enter setup mode as described above, then **fully release BOOT**.
2. Hold BOOT again for about five seconds. Release it when you see the three slow white pulses.
3. The device clears the connection information, restarts, and enters setup mode again.

The LED count and dynamic trend setting are preserved. These are two separate long presses; one continuous press cannot trigger both setup mode and clearing connection information.

## 7. Optional: print a board enclosure

Once wiring, flashing, and Wi-Fi setup are working, you can add an enclosure for the controller board.

The model is by **Mattia Carli**, available on [MakerWorld](https://makerworld.com/zh/models/2008412-case-for-esp32-c3-pro-mini-esp32-c3fh4#profileId-2163305). The original STL contains both the body and the lid. This project also provides them as separate files:

- [Original: body and lid in one file](models/esp32-c3-pro-mini/Case_ESP32-C3_PRO_MINI_V01.stl)
- [Body only](models/esp32-c3-pro-mini/Case_ESP32-C3_PRO_MINI_V01_Body.stl)
- [Lid only](models/esp32-c3-pro-mini/Case_ESP32-C3_PRO_MINI_V01_Lid.stl)

If your printing service does not accept the combined file, upload the body and lid separately and print one of each. This model holds the controller board only. See the [model notes](models/esp32-c3-pro-mini/README.en.md) for dimensions, changes in the split files, and the original license.

## Troubleshooting

### Serial port will not open

`Failed to execute 'open' on 'SerialPort'` means the browser could not open the serial port. This can happen before writing or while reconnecting after writing, so the error alone does not tell you whether firmware was written.

1. Close the installation dialog and any other flashing pages or serial tools connected to the board.
2. Unplug the board, reconnect it to the computer, select “Connect and install,” and choose the port again.
3. If it still fails, try a known working USB data cable connected directly to another USB port on the computer.

### The board is missing from the serial port list

First check that the USB cable carries data. If the port still does not appear, try entering flashing mode: unplug USB, hold BOOT while reconnecting USB, wait about two seconds, then release BOOT and select the port again.

This is a flashing recovery procedure. For everyday Wi-Fi setup, power the board normally first, then hold BOOT.

For more serial port, driver, and manual flashing instructions, see [installation and flashing troubleshooting](INSTALL.en.md).

### Cannot find `Suger-RGB-XXXX`

A configured device does not keep its hotspot open during normal startup. Power it normally, hold BOOT for about five seconds, release it, and scan for Wi-Fi networks again on your phone.

If the hotspot is still missing, confirm that the board is a **Pro Mini**, move your phone closer, and try another phone. A white chase means the device is entering setup mode; the light effect alone does not prove that the hotspot is broadcasting successfully.

If the hotspot appears with computer power but not with an external supply, use the same cable to compare the two power sources. Then try a known working power supply and cable to help narrow down the cause.

### The phone joins the hotspot, but the page will not open

Check that the phone is still connected to `Suger-RGB-XXXX` and has not switched back to your home Wi-Fi. If needed, temporarily disable mobile data or automatic switching to a network with Internet access. Enter **`http://192.168.4.1/`** in the browser's address bar, not its search field.

### Validation fails, or the save button is disabled

Validation must succeed before you can save. Changing any setting requires validation again.

| Message | What to check first |
| --- | --- |
| Incorrect Wi-Fi name or password, or connection timeout | Check for a 2.4 GHz home network, correct name and password, and a signal within range of the device |
| `401` / `403` | Check that Nightscout allows anonymous data reads; being able to open the home page does not mean the data API allows anonymous access |
| Nightscout timeout or connection failure | Check the address, HTTPS certificate, and whether your home network can reach the site |
| No glucose data, or an old record | Check that the CGM is still uploading to Nightscout and that the latest record has the expected timestamp |

To check the Nightscout website from your phone, restore the phone's normal Internet connection first. Rejoin the device hotspot afterward to continue setup.

### No LEDs light up, or only some do

Disconnect power first. Check that `5V`, `GND`, and `GPIO4 → DIN` are connected correctly and securely. Power the device, open the setup page, and check the actual LED count. Before the first setup, the default is 30 LEDs; enter the actual count for a strip, ring, or matrix with more than 30 LEDs.

If a section still does not light up, check the connections before that section and the data direction. Do not use the LEDs' `DOUT` output as the input.

### The LEDs keep showing white breathing

Just after startup, the device may not have read its first record yet. If white breathing continues, check your home Wi-Fi and Nightscout. When the latest Nightscout record is more than 10 minutes old, restarting or reflashing cannot make that record current.

---

[Back to project home](../README.md) · [Web installer](https://rgb.sidluo.com/installer/) · [Installation and flashing troubleshooting](INSTALL.en.md)

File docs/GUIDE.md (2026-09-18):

# Suger RGB 详细使用教程

[English](GUIDE.en.md) · [项目首页](../README.zh-CN.md) · [网页安装器](https://rgb.sidluo.com/installer/)

第一次制作，可以按下面的顺序完成：**准备材料 → 接线 → 用电脑刷写 → 用手机配网 → 放到日常使用的位置。** 不需要安装开发环境，也不需要修改代码。

已经做好设备、只想更换 Wi-Fi 或修改设置，可以直接看[修改设置](#修改设置)。遇到问题，可以跳到[常见问题](#常见问题)。

## ⚠️ 不要使用 ESP32-C3 Super Mini，请使用 ESP32-C3 Pro Mini

> [!WARNING]
> **请勿购买或使用 ESP32-C3 Super Mini（SuperMini）制作本项目。** 本项目实测曾遇到搜不到配网热点、Wi-Fi 连接不稳定等问题，换成 **ESP32-C3 Pro Mini** 后恢复正常。即使刷写成功，也不能据此判断无线连接正常。

> [!IMPORTANT]
> Suger RGB 是开源社区 DIY 项目，只把 CGM 已有的数据转换成灯光，不能替代 CGM 原始读数、报警、医疗判断或治疗建议。设备的搭建和使用由用户自行负责。

## 1. 准备材料

| 需要准备 | 具体要求 |
| --- | --- |
| 主板 | **ESP32-C3 Pro Mini，4 MB Flash** |
| 灯 | **5V WS2812B** 灯带、灯环或灯板，1–128 颗灯珠 |
| 接线材料 | 连接 5V、GND 和数据输入的三条线；按所购主板和灯具准备焊接或连接材料 |
| USB 数据线 | 能传输数据，不能只支持充电 |
| 电脑 | 用于网页刷写，建议使用桌面版 Chrome 或 Edge |
| 手机 | 用于连接设备热点、填写配置 |
| 日常电源 | USB 5V / 2A 电源 |
| 家庭网络 | 能访问 Nightscout 的 2.4 GHz Wi-Fi |
| Nightscout | 正在接收血糖数据的 HTTPS 站点，并允许匿名读取数据 |

在淘宝搜索 `esp32-c3-mini-pro` 和 `ws2812b` 可以找到对应材料。**请再次确认购买的是 Pro Mini，不是 Super Mini。**

还没有 Nightscout，可以先了解 [Nightscout for Cloudflare](https://github.com/sid-luo/nightscout-for-cloudflare#rgb)。当前固件没有 API_SECRET 或 Token 输入框，不能连接必须凭口令或 Token 才能读取数据的站点。

外壳可以在设备正常工作后再安装。先确认灯珠数量，并在手机正常联网时检查 Nightscout 是否正在更新。

ESP32-C3 Pro Mini 正面与背面

上图左侧是正面，右侧是背面。下面的接线图使用**背面视角，USB 接口朝上**。

## 2. 接好三条线

**接线前先断开 USB 和其他电源。**

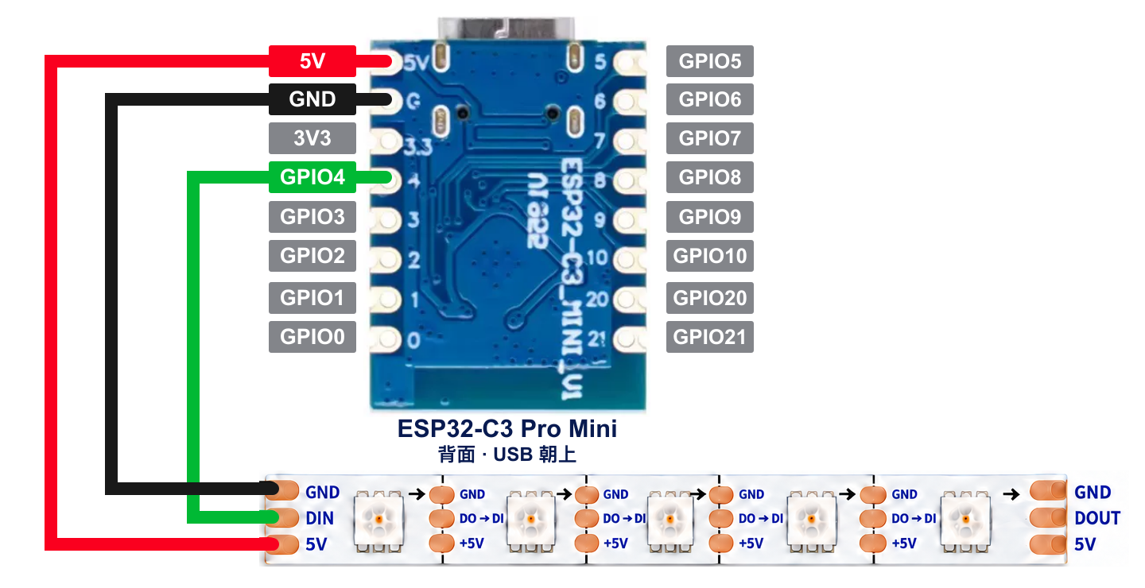
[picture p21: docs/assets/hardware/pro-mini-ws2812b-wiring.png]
ESP32-C3 Pro Mini 与 WS2812B 灯带接线图


| 主板引脚 | 连接到灯具 | 用途 |
| --- | --- | --- |
| `5V` | `5V` 或 `+5V` | 供电正极 |
| `GND` | `GND` 或 `G` | 共地 |
| `GPIO4`（板上标为 `4`） | `DIN` 或 `DI` | 数据输入 |

灯带箭头表示数据传递方向：数据从主板进入 `DIN`，再向后面的灯珠传递。`DOUT` 或 `DO` 是输出端，不能代替输入端。**灯带焊盘的位置可能不同，按实物上的文字接线，不要只看焊盘在上面还是下面。**

灯环和灯板同样连接这三条线。检查接点是否牢固、相邻焊盘是否连锡，再用 USB 数据线连接电脑。

<details>
<summary>查看完整引脚图和灯带实物参考</summary>

ESP32-C3 Pro Mini 引脚图，背面视角

WS2812B 灯带实物参考，每两颗灯珠之间有焊盘

</details>

### 实物接线参考

**主板接线近照**

主板接线近照

**主板与连接线**

主板与连接线

**主板与灯带连接全貌**

主板与灯带连接全貌

## 3. 用电脑刷写固件

建议使用电脑上的 Chrome 或 Edge，并准备一根支持数据传输的 USB 线。

### 3.1 打开安装器

用 USB 数据线把主板连接到电脑，打开 [Suger RGB 网页安装器](https://rgb.sidluo.com/installer/)，点击 **“连接设备并安装”**。

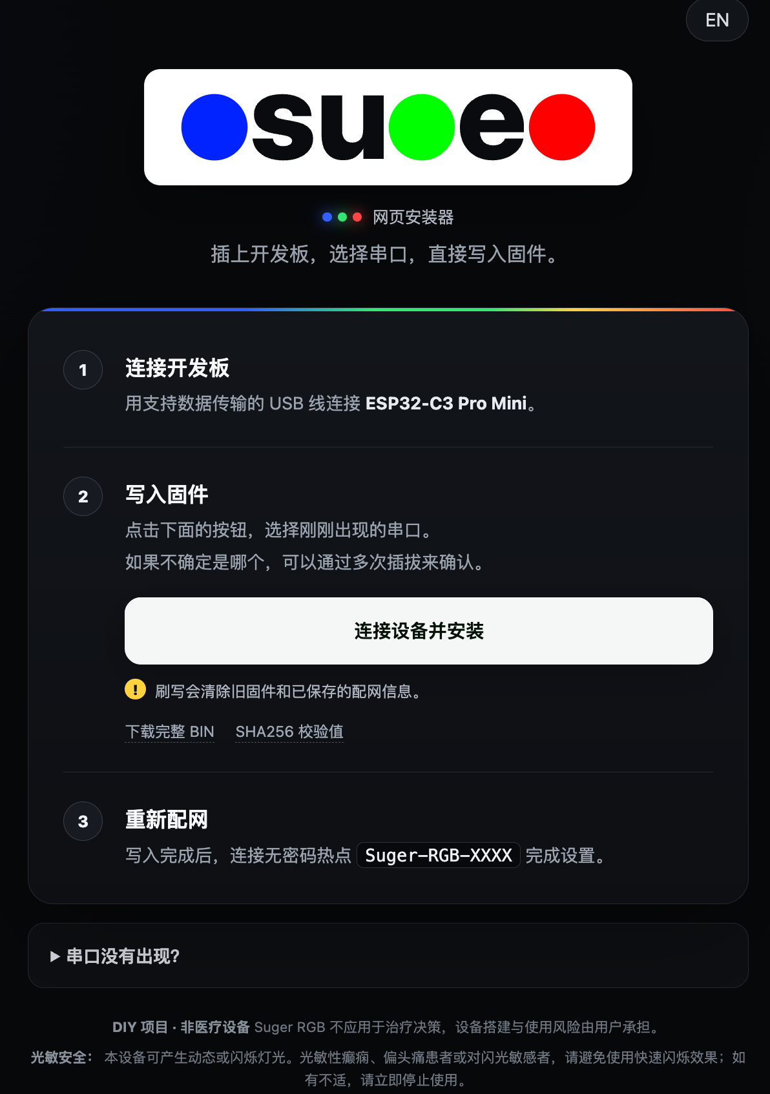
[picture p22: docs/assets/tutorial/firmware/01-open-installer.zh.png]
网页安装器，点击连接设备并安装


### 3.2 通过插拔确认串口

浏览器会弹出串口列表。如果不确定哪一个是主板，可以先拔下主板，再重新插入，观察哪个条目消失后又出现。**这个对照只在开始写入前进行。**

| 拔下主板 | 重新插入主板 |
| --- | --- |
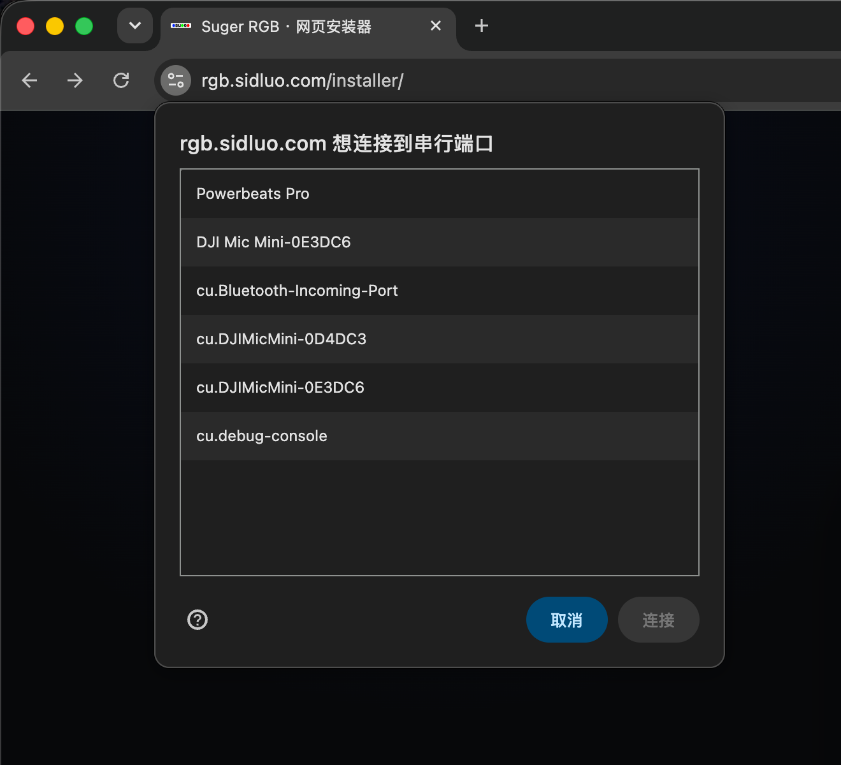
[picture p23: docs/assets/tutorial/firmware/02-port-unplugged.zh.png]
拔下主板后，列表中没有主板的 USB 串口
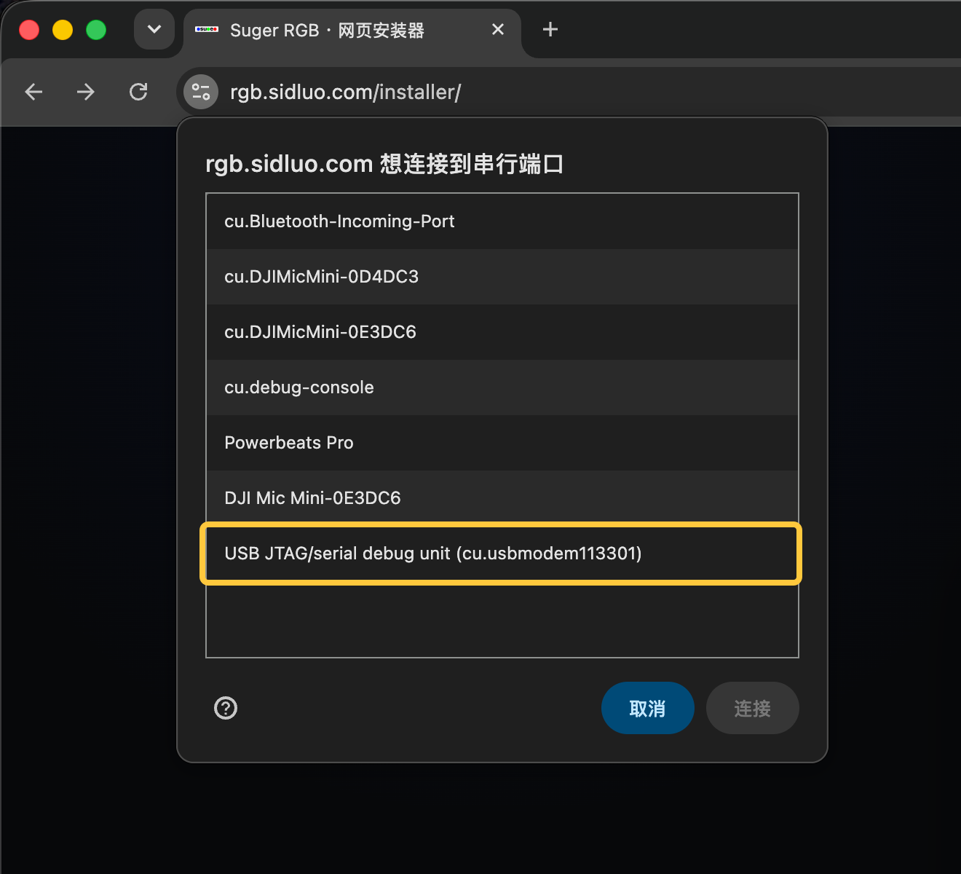
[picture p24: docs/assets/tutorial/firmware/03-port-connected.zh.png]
插入主板后，列表中新增 USB JTAG 串口
|  |  |
| 列表中没有主板的 USB 串口。 | 新增了 `USB JTAG/serial debug unit` 条目。 |

选择随插拔消失、重新出现的条目，再点击 **“连接”**。实际串口名称和编号因电脑而异，不必与截图中的编号一致。如果列表没有刷新，点击 **“取消”**，再点 **“连接设备并安装”** 重新查看。

### 3.3 选择安装

在弹窗中点击 **“安装 Suger RGB”**。

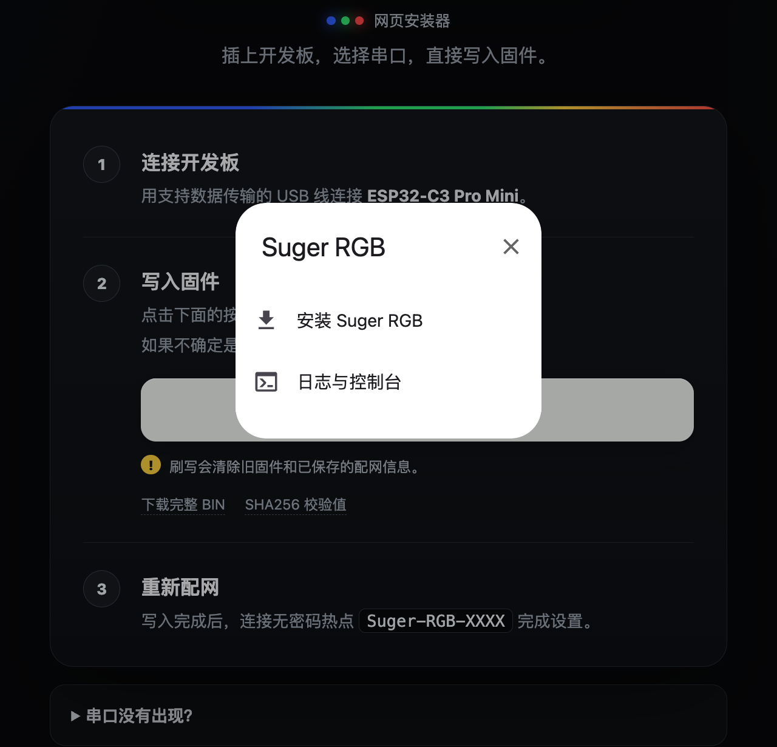
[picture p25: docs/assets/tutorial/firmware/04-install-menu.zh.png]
选择安装 Suger RGB


### 3.4 确认安装

确认后点击 **“安装”**。**本网页刷写会清除旧固件和已经保存的配网信息。**

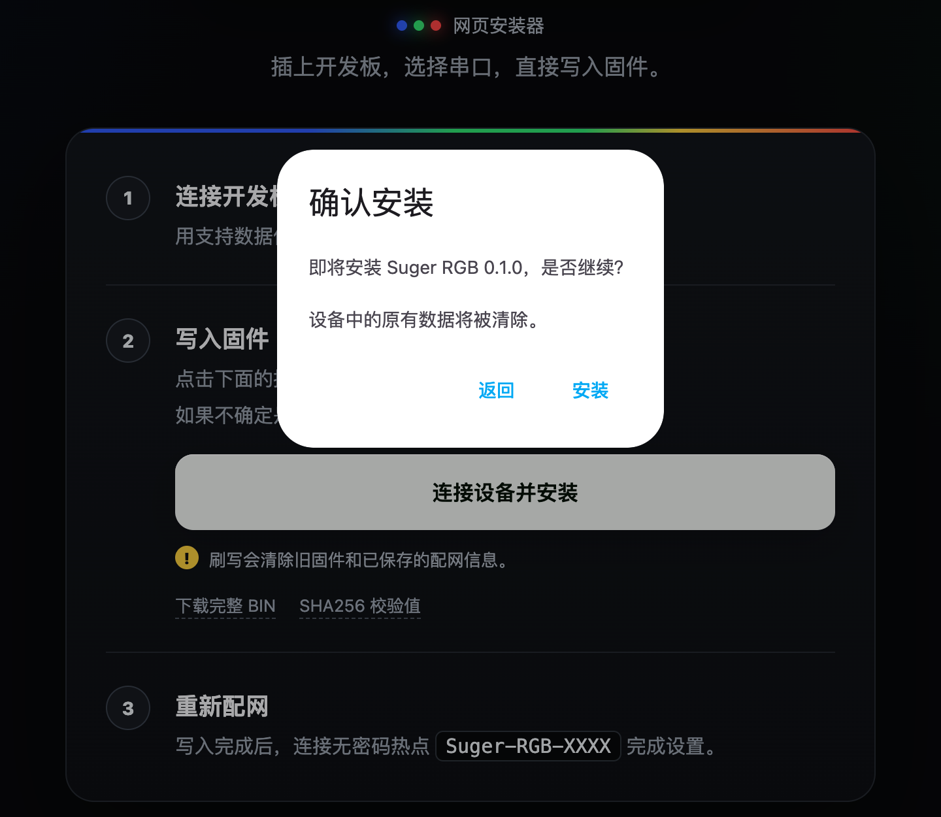
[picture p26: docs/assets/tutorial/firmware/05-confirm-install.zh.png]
确认安装弹窗，点击安装开始写入


### 3.5 等待写入

保持页面打开，等待进度完成。写入期间不要拔下 USB 线。

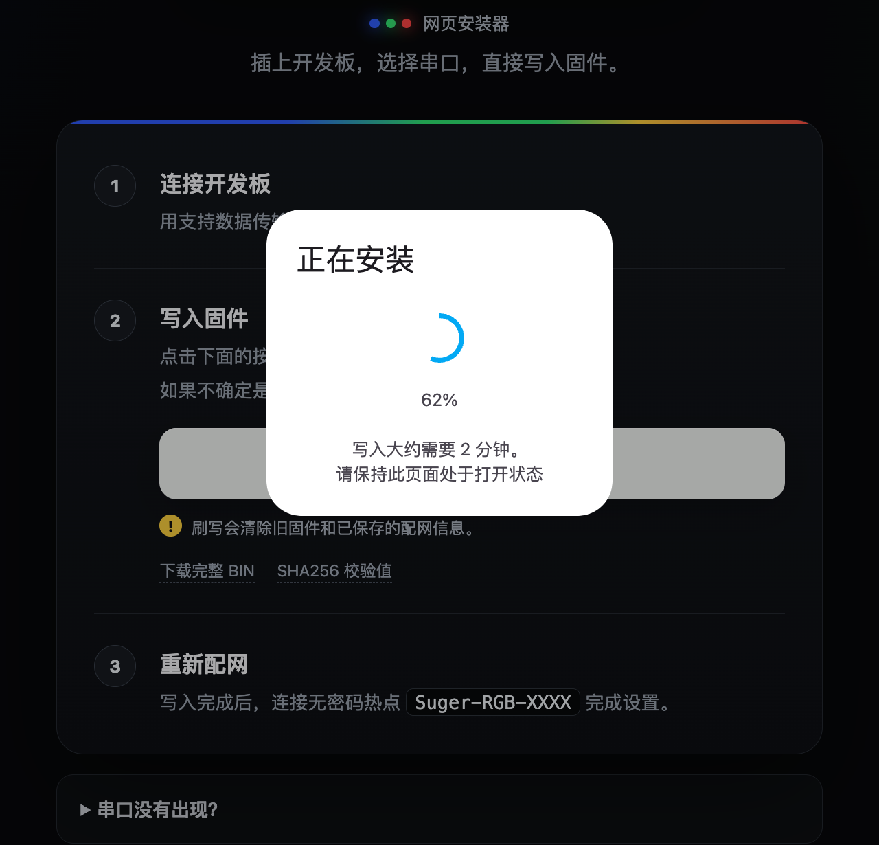
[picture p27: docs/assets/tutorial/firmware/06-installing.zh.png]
固件正在写入，等待进度完成


### 3.6 确认完成

看到 **“固件安装完成！”** 后，点击 **“下一步”**。

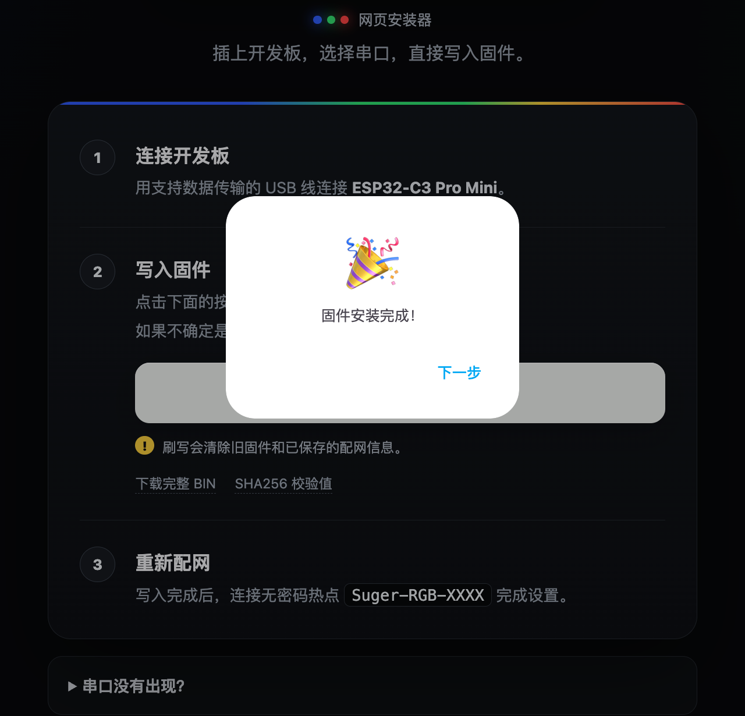
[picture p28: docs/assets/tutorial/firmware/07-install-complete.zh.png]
固件安装完成，点击下一步


设备重启后会进入首次配网状态。接线正常的灯会显示低亮度白色跑马灯；接下来按[用手机完成配网](#4-用手机完成配网)连接 `Suger-RGB-XXXX` 热点。

如果提示“无法打开串口”，先看[串口打开失败](#串口打开失败)。只有页面明确报告安装完成，才算刷写完成；选到串口不等于已经写入。

## 4. 用手机完成配网

### 连接设备热点

尚未保存完整配网信息的设备，启动后会自动进入配网状态。已经配置过的设备，需要先[长按 BOOT 进入配网](#修改设置)。

1. 打开手机的 Wi-Fi 设置，连接 **`Suger-RGB-XXXX`**。末尾字符因设备而异，热点没有密码。
2. 手机若提示“无互联网连接”，选择继续连接。此时是手机在直接连接灯的设置页面。
3. 等待配网页弹出。没有自动弹出时，保持连接该热点，在浏览器地址栏输入 **`http://192.168.4.1/`**。

下面的 Wi-Fi 列表中已出现设备热点，点击 **`Suger-RGB-XXXX`** 即可连接。

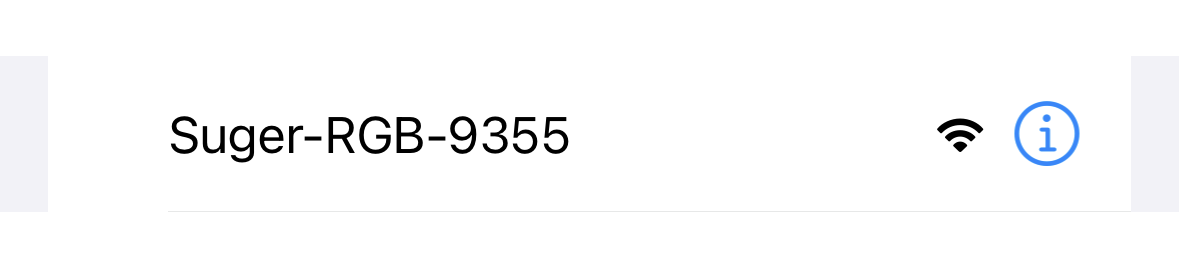
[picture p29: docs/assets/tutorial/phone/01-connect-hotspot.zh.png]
手机 Wi-Fi 列表中可选择的 Suger-RGB-XXXX 设备热点


### 填写设置

配网页右上角可切换中文和英文。

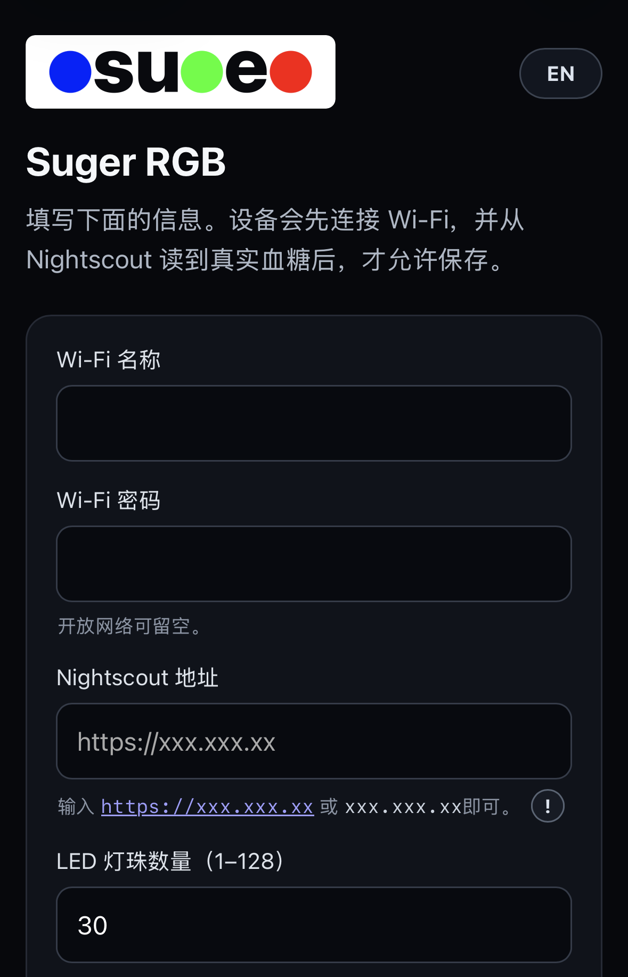
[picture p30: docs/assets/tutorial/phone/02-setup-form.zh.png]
中文配网页，填写 Wi-Fi、Nightscout 地址和 LED 灯珠数量


| 页面项目 | 应填写什么 |
| --- | --- |
| Wi-Fi 名称 | 家中 **2.4 GHz Wi-Fi** 的名称，不是 `Suger-RGB-XXXX` |
| Wi-Fi 密码 | 上面这个家庭 Wi-Fi 的密码；开放网络可留空 |
| Nightscout 地址 | 例如 `https://example.com`，也可以只填 `example.com` |
| LED 灯珠数量（1–128） | 实际连接的灯珠总数，例如 8×8 灯板填写 `64` |
| 动态趋势提示 | 默认开启；关闭后，普通范围内只显示血糖颜色常亮 |

Nightscout 地址不需要手动添加 API 路径，设备会自动处理。当前只支持 HTTPS。

动态趋势开关不会关闭极低、极高血糖对应的特殊灯效，具体见[日常灯光含义](#5-日常灯光含义)。

### 测试灯效

点击 **“动态趋势提示”旁的 `!`** 展开测试区，再点击低／高血糖卡片或趋势箭头，查看实物灯效。再次点击 `!` 收起测试区，即可停止预览。

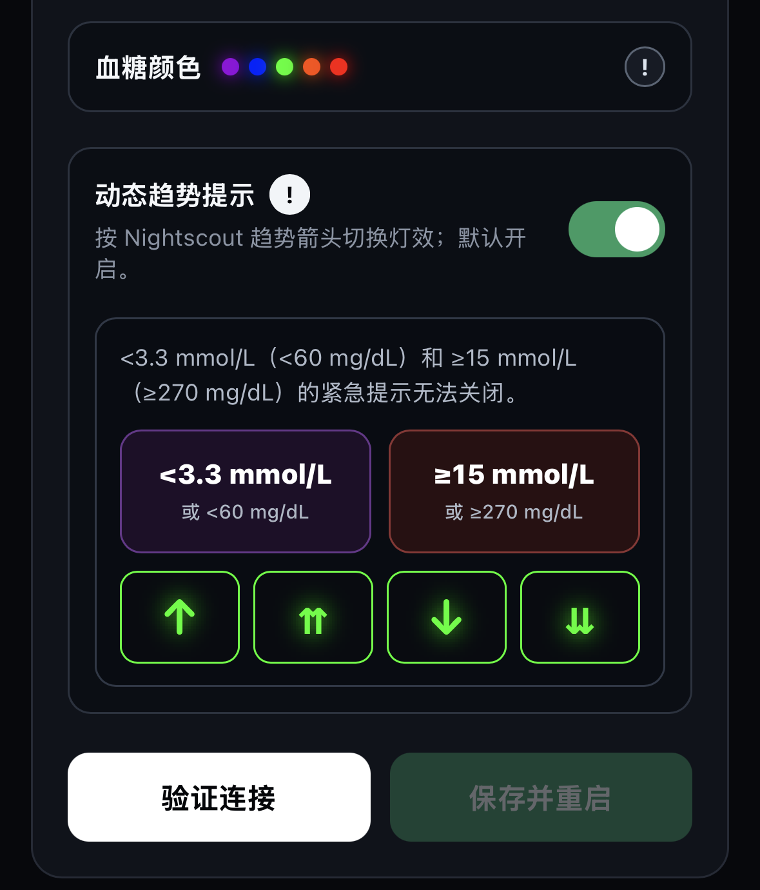
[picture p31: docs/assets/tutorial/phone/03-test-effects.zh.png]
展开动态趋势提示，点击低高血糖卡片或趋势箭头测试实物灯效


测试只预览灯效，不会修改 Nightscout 中的血糖记录。

### 验证并保存

1. 点击 **“验证连接”**。设备会尝试连接家庭 Wi-Fi，并向 Nightscout 请求血糖数据。
2. 验证成功后，页面会显示读到的血糖、数据时间和趋势。先确认这些信息符合预期。

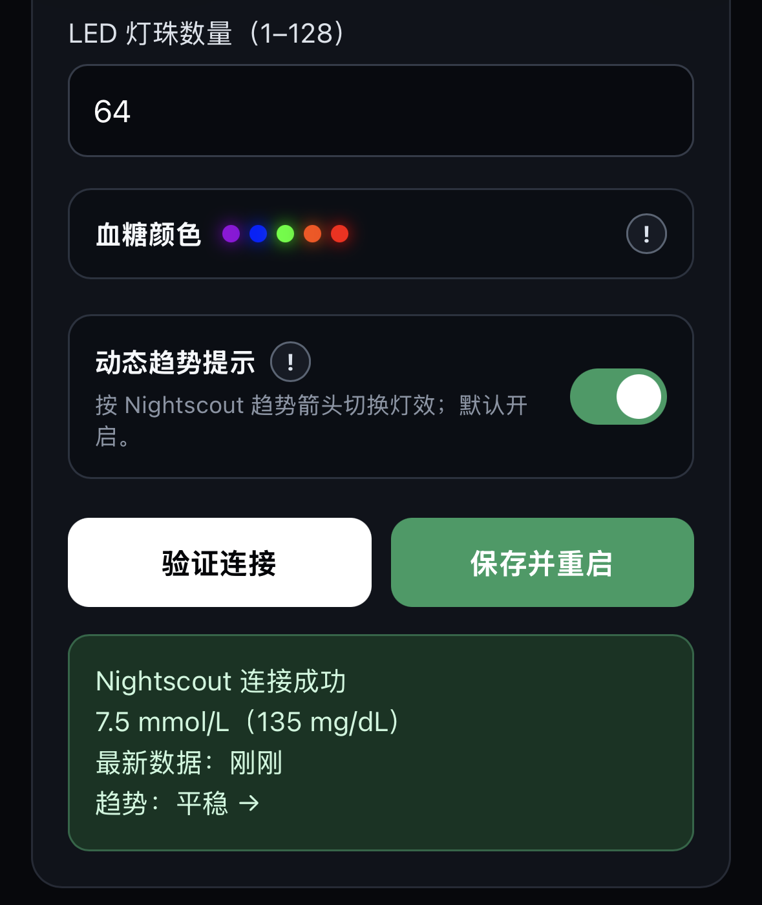
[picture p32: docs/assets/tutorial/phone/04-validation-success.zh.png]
Nightscout 连接成功，显示血糖和趋势，保存并重启按钮已启用


3. 点击 **“保存并重启”**。只验证、不保存，设置不会完成。
4. 等待设备重启。手机可以重新连接日常使用的 Wi-Fi。

**完成后应看到**：设备连接家庭 Wi-Fi，读到有效数据后按血糖和趋势显示灯光。正常运行时，配网热点和设置页面会关闭。

如果页面提示数据已经超过 10 分钟，即使能保存，灯也会显示白色呼吸。先检查 Nightscout 的数据更新情况。

## 5. 日常灯光含义

设备大约每分钟从 Nightscout 读取一次数据。灯光反映的是 Nightscout 已收到的记录，CGM 上传或网络延迟也会影响显示。

### 血糖颜色

| mmol/L | mg/dL | 颜色 |
| ---: | ---: | --- |
| `<3.5` | `<63` | 紫色 |
| `3.5–<4.4` | `63–79` | 蓝色 |
| `4.4–<8.5` | `80–152` | 绿色 |
| `8.5–<10` | `153–179` | 橙色 |
| `≥10` | `≥180` | 红色 |

### 趋势灯效

开启“动态趋势提示”时，普通范围内按下面的对应关系显示：

| Nightscout 趋势 | 灯光变化 |
| --- | --- |
| `↑` 上升 | 当前血糖颜色柔和呼吸 |
| `⇈` 快速上升 | 呼吸速度更快 |
| `↓` 下降 | 反向渐进填充 |
| `⇊` 快速下降 | 反向彗星 |
| `→`、`↗`、`↘` 或其他趋势 | 当前血糖颜色常亮 |

### 特殊显示

| 状态 | 灯光表现 |
| --- | --- |
| 血糖低于 `60 mg/dL`（约 `3.3 mmol/L`） | 紫色双脉冲，优先于普通趋势灯效 |
| 血糖达到 `270 mg/dL`（`15 mmol/L`）或以上 | 彩色闪烁（Twinklefox），优先于普通趋势灯效 |
| 刚启动还没读到数据，或数据已经过期 | 白色呼吸 |
| 正在配网 | 低亮度白色追逐（跑马灯） |
| 清除连接信息时 | 三次缓慢白光变化 |

极低、极高血糖的特殊灯效始终保留，关闭动态趋势提示也不会关闭它们。白色呼吸不是血糖区间颜色；正常运行中，数据超过 10 分钟未更新会进入这个状态。

设置保存后可以断开电脑，改用日常 USB 电源。断电不会清除设置，再次上电会自动连接已经保存的家庭 Wi-Fi。

## 6. 修改设置与重新配网

### 修改设置

更换家庭 Wi-Fi，或需要修改 Nightscout 地址、灯珠数量、动态趋势提示时：

1. 让设备正常通电。
2. 按住板上的 **BOOT 约 5 秒**，看到白色追逐后松开。
3. 手机连接 `Suger-RGB-XXXX`，打开配网页或 `http://192.168.4.1/`。
4. 修改设置，重新点击 **“验证连接”**，再点击 **“保存并重启”**。

如果 Wi-Fi 名称没有改变，密码框留空会继续使用已保存的密码。更换到另一个有密码的 Wi-Fi 时，需要填写新密码。

正常运行时，设备在家庭 Wi-Fi 中的 IP 不是管理入口。修改设置需要先用实体 BOOT 按键进入配网状态。

### 清除已保存的连接信息

只有想清除家庭 Wi-Fi 和 Nightscout 地址时，才需要以下操作：

1. 先按上面的步骤进入配网状态，并**完全松开 BOOT**。
2. 再次按住 BOOT 约 5 秒，看到三次缓慢白光变化后松开。
3. 设备会清除连接信息并重启，再次进入配网状态。

灯珠数量和动态趋势设置会保留。这是两次独立长按；一直按住同一次不会连续触发进入配网和清除信息。

## 7. 可选：打印主板保护壳

确认接线、刷写和配网都正常后，可以给主板加装保护壳。

模型来自 **Mattia Carli** 的 [MakerWorld 作品](https://makerworld.com/zh/models/2008412-case-for-esp32-c3-pro-mini-esp32-c3fh4#profileId-2163305)。原版把盒体和盖子放在同一个 STL 中，本项目另外提供了拆分文件：

- [原版：盒体和盖子在同一文件中](models/esp32-c3-pro-mini/Case_ESP32-C3_PRO_MINI_V01.stl)
- [单独的盒体](models/esp32-c3-pro-mini/Case_ESP32-C3_PRO_MINI_V01_Body.stl)
- [单独的盖子](models/esp32-c3-pro-mini/Case_ESP32-C3_PRO_MINI_V01_Lid.stl)

打印平台不接受组合文件时，分别上传盒体和盖子，两件都需要打印。这个模型只容纳主板；尺寸、拆分说明及原作者许可见[模型说明](models/esp32-c3-pro-mini/README.md)。

## 常见问题

### 串口打开失败

出现 `Failed to execute 'open' on 'SerialPort'` 或“无法打开串口”时，表示浏览器没能打开串口。它可能发生在写入前，也可能发生在写入后的重新连接阶段，单凭这条报错不能判断是否已写入。

1. 关闭安装对话框，以及其他正在连接该主板的刷写网页或串口工具。
2. 拔下主板，重新插入电脑，再点击“连接设备并安装”，重新选择串口。
3. 仍然失败时，换一根确认能传数据的 USB 线，直接连接电脑的另一个 USB 接口。

### 串口列表里没有主板

先确认 USB 线能传数据。如果仍不出现，可尝试进入刷写模式：拔掉 USB，按住 BOOT 后重新插入 USB，等待约两秒，再松开 BOOT，然后重新选择串口。

这是刷写恢复操作。日常重新配网时，应当先正常通电，再长按 BOOT。

更多串口、驱动和手动刷写步骤见[安装与刷写排查](INSTALL.md)。

### 搜不到 `Suger-RGB-XXXX`

已经配过网的设备，正常启动时不会一直显示热点。先让设备正常通电，再长按 BOOT 约 5 秒并松开，重新扫描手机 Wi-Fi。

如果仍搜不到，确认主板确实是 **Pro Mini**，把手机靠近设备，并尝试另一台手机。白色追逐表示设备正在进入配网流程，不能单凭灯效断定热点已成功广播。

如果电脑供电能搜到、换外部电源后搜不到，用同一根线分别测试两种电源，再尝试一组已知正常的电源和线，便于定位问题。

### 手机连上热点，但打不开页面

先确认手机仍连着 `Suger-RGB-XXXX`，没有自动切回家庭 Wi-Fi。必要时暂时关闭移动数据或“自动切换到可上网网络”，在浏览器地址栏输入 **`http://192.168.4.1/`**，不要输入到搜索框。

### 验证连接失败，或者保存按钮不能点击

保存前必须先验证成功；修改任何设置后都需要重新验证。

| 页面提示 | 先检查什么 |
| --- | --- |
| Wi-Fi 名称、密码错误或连接超时 | 家庭网络是否为 2.4 GHz，名称和密码是否正确，设备是否在信号范围内 |
| `401` / `403` | Nightscout 是否允许匿名读取数据；能打开网站首页不代表数据接口允许匿名读取 |
| Nightscout 超时或连接失败 | 地址、HTTPS 证书及家庭网络能否访问该站点 |
| 没有血糖数据或记录过期 | CGM 是否仍在向 Nightscout 上传，最新记录时间是否正常 |

如需用手机检查 Nightscout 网站本身，先让手机恢复正常联网；查完后再连接设备热点继续配网。

### 灯完全不亮，或只有一部分亮

先断电检查 `5V`、`GND` 和 `GPIO4 → DIN` 是否接对、接牢。通电后进入配网页，核对实际灯珠数量。首次配置前默认按 30 颗显示；超过 30 颗的灯具应在配网页填写实际数量。

如果仍有某一段不亮，继续检查那一段之前的接点和数据方向。不要把灯的输出端 `DOUT` 当成输入端。

### 灯一直白色呼吸

刚启动时可能还没读到第一条数据；如果一直这样，检查家庭 Wi-Fi 和 Nightscout。Nightscout 中的记录已经超过 10 分钟时，反复重启或刷写也不会让旧数据变新。

---

[返回项目首页](../README.zh-CN.md) · [网页安装器](https://rgb.sidluo.com/installer/) · [安装与刷写排查](INSTALL.md)

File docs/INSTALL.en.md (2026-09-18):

# Install Suger RGB

## ⚠️ DO NOT USE ESP32-C3 SUPER MINI — USE ESP32-C3 PRO MINI

> [!WARNING]
> **Do not buy or use an ESP32-C3 Super Mini (SuperMini) for this project.** These boards may have unreliable Wi-Fi, an undiscoverable setup hotspot, or failed Wi-Fi setup. A successful firmware flash does not guarantee working Wi-Fi.
>
> These issues occurred during this project's testing and were resolved by switching to an **ESP32-C3 Pro Mini**. **Choose the ESP32-C3 Pro Mini for this project.**

[简体中文](INSTALL.md) · [Back to project home](../README.md)

The browser installer is recommended. It verifies the chip and writes the bootloader, partition table, and application as one complete ESP32-C3 image. ESP-IDF and command-line tools are not required.

## Browser installation

### Requirements

- ESP32-C3 Pro Mini with 4 MB flash;
- a USB data cable;
- a Windows, macOS, or Linux computer;
- desktop Chrome or Edge;
- a stable connection to load the page and download the roughly 1 MB image.

Safari and iPhone do not support browser serial flashing. Close serial monitors, Arduino IDE, PlatformIO, and any other application that may already own the port.

### Steps

1. Open the [Suger RGB web installer](https://rgb.sidluo.com/installer/).
2. Connect the board with the USB data cable.
3. Select “Install Suger RGB.”
4. Choose the ESP32-C3 serial port in the browser prompt.
5. Confirm installation. Browser flashing erases the previous firmware and saved setup details.
6. Confirm and wait for the board to restart.

The installer accepts ESP32-C3 devices only and refuses another detected chip family. Flashing happens directly between the browser and the local USB device; the page does not receive Wi-Fi passwords or Nightscout configuration. Setup is required again after every browser flash.

### After flashing

On first boot, the LEDs show a low-brightness white chase and the board creates the open network `Suger-RGB-XXXX`:

1. Join that network from a phone;
2. wait for the captive page, or open `http://192.168.4.1/`;
3. enter home Wi-Fi, the Nightscout address, and pixel count;
4. validate a real glucose reading and save.

The device restarts and closes the setup page after saving. Its LAN address does not expose an administration page during normal operation. To change settings later, physically hold BOOT for about five seconds.

## The browser cannot find the board

Try these in order:

1. use a known USB data cable;
2. try another computer USB port and avoid an unstable hub;
3. close every application or page using the serial port;
4. unplug the board, hold BOOT while reconnecting USB, then release BOOT;
5. if the board has RST, hold BOOT, tap RST, then release BOOT;
6. start installation again and select the newly appearing port.

Boards with an external USB-to-serial bridge may require a CH34x, CP210x, or vendor driver. ESP32-C3 native USB Serial/JTAG normally needs no additional driver.

## Build from source

The project uses ESP-IDF 5.4.x:

```bash
. ~/esp/esp-idf/export.sh
idf.py set-target esp32c3
idf.py build
idf.py -p /dev/cu.usbmodemXXXX flash monitor
```

Windows ports normally look like `COM5`. Exit the monitor with `Ctrl+]`.

## Flash the merged image manually

The complete image used by the web installer is:

```text
docs/installer/firmware/suger-rgb-esp32c3.bin
```

With ESP-IDF or esptool installed, write it at address `0x0`:

```bash
esptool.py --chip esp32c3 --port PORT write_flash 0x0 \
  docs/installer/firmware/suger-rgb-esp32c3.bin
```

This merged image is the same one used by the browser installer. It overwrites saved setup data, so configuration is required again.

Each release also provides `SHA256SUMS.txt` for download verification.

## Update the web-installer image

Maintainers run this from an ESP-IDF environment:

```bash
./tools/package_web_firmware.sh
```

The script rebuilds the project, creates the merged image beginning at `0x0`, validates it, and updates the SHA-256 file. Complete [`RELEASE_CHECKLIST.md`](RELEASE_CHECKLIST.md) before publishing.

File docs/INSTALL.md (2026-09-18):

# 安装 Suger RGB

## ⚠️ 不要使用 ESP32-C3 Super Mini，请使用 ESP32-C3 Pro Mini

> [!WARNING]
> **请勿购买或使用 ESP32-C3 Super Mini（SuperMini）制作本项目。** 这类板子可能出现 Wi-Fi 不稳定、搜不到配网热点或配网失败等问题，即使固件刷写成功也可能无法正常联网。
>
> 本项目实测曾遇到上述问题，换用 **ESP32-C3 Pro Mini** 后恢复正常。**请直接选用 ESP32-C3 Pro Mini。**

[English](INSTALL.en.md) · [返回项目首页](../README.zh-CN.md)

推荐使用网页安装器。它会检查芯片型号，并把 bootloader、分区表和应用程序作为一个完整固件写入 ESP32-C3；不需要安装 ESP-IDF 或使用命令行。

## 网页安装

### 准备

- ESP32-C3 Pro Mini，4 MB Flash；
- 能传输数据的 USB 线；
- Windows、macOS 或 Linux 电脑；
- 桌面版 Chrome 或 Edge；
- 稳定的网络连接，用于打开页面和下载约 1 MB 固件。

Safari 与 iPhone 不支持网页串口刷写。开始前请关闭串口监视器、Arduino IDE、PlatformIO 等可能占用串口的软件。

### 操作

1. 打开 [Suger RGB 网页安装器](https://rgb.sidluo.com/installer/)。
2. 使用 USB 数据线连接开发板。
3. 点击“安装 Suger RGB”。
4. 在浏览器弹窗中选择 ESP32-C3 对应的串口。
5. 确认安装；网页刷写会清除旧固件和已经保存的配网信息。
6. 确认安装并等待开发板自动重启。

安装器只接受 ESP32-C3；检测到其他芯片时不会开始写入。刷写在浏览器与本地 USB 设备之间完成，安装页不会获得 Wi-Fi 密码或 Nightscout 配置。每次网页刷写完成后都需要重新配网。

### 刷写完成后

首次启动时，灯会显示低亮度白光追逐，并创建无密码热点 `Suger-RGB-XXXX`：

1. 用手机连接该热点；
2. 等待配网页自动弹出，或访问 `http://192.168.4.1/`；
3. 填写家庭 Wi-Fi、Nightscout 地址和灯珠数量；
4. 验证读到真实血糖后保存。

保存后设备重启并关闭设置网页。正常运行期间，局域网 IP 不提供管理入口；以后如需修改，长按实体 BOOT 按键约 5 秒重新进入配网状态。

## 浏览器找不到开发板

依次检查：

1. 换一根确认可以传数据的 USB 线；
2. 换一个电脑 USB 接口，避免无供电或不稳定的扩展坞；
3. 关闭所有占用串口的软件和其他网页；
4. 拔掉开发板，按住 BOOT 后重新插入 USB，再松开 BOOT；
5. 如果开发板带 RST 按键，也可以按住 BOOT、短按 RST、再松开 BOOT；
6. 重新点击安装并选择新出现的串口。

部分使用外置 USB 转串口芯片的开发板可能需要 CH34x、CP210x 或厂商驱动；ESP32-C3 原生 USB Serial/JTAG 通常不需要额外驱动。

## 从源码编译

项目使用 ESP-IDF 5.4.x：

```bash
. ~/esp/esp-idf/export.sh
idf.py set-target esp32c3
idf.py build
idf.py -p /dev/cu.usbmodemXXXX flash monitor
```

Windows 串口通常类似 `COM5`。退出监视器使用 `Ctrl+]`。

## 使用合并固件手动烧录

网页安装器使用的完整固件位于：

```text
docs/installer/firmware/suger-rgb-esp32c3.bin
```

安装 ESP-IDF 或 esptool 后可以写入地址 `0x0`：

```bash
esptool.py --chip esp32c3 --port PORT write_flash 0x0 \
  docs/installer/firmware/suger-rgb-esp32c3.bin
```

该合并固件与网页安装相同，会覆盖旧配置，写入后需要重新配网。

每次发布都会同时提供 `SHA256SUMS.txt`，可用于核对下载文件是否完整。

## 更新网页安装固件

维护者在 ESP-IDF 环境中运行：

```bash
./tools/package_web_firmware.sh
```

脚本会重新编译项目、生成地址从 `0x0` 开始的合并固件、执行镜像校验，并更新 SHA-256 文件。发布前还应完成 [`RELEASE_CHECKLIST.md`](RELEASE_CHECKLIST.md)。

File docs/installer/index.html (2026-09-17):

EN

Suger RGB

网页安装器

插上开发板，选择串口，直接写入固件。

1

## 连接开发板

用支持数据传输的 USB 线连接 ESP32-C3 Pro Mini。

2

## 写入固件

点击下面的按钮，选择刚刚出现的串口。如果不确定是哪个，可以通过多次插拔来确认。

连接设备并安装 请使用桌面版 Chrome、Edge 或最新版 Firefox 打开此页面。 安装器必须通过 HTTPS 或 localhost 打开。

!刷写会清除旧固件和已保存的配网信息。

3

## 重新配网

写入完成后，连接无密码热点 Suger-RGB-XXXX 完成设置。

串口没有出现？

多数情况是数据线问题，请按顺序尝试：

1. 换一根能让手机和电脑互传照片或文件的 USB 数据线；只能充电的线不会出现串口。
2. 拔掉开发板，按住板上的 BOOT 键，再插入 USB；等待两秒后松开 BOOT，然后重新点击安装。
3. 最后，关闭可能占用串口的软件，例如 Arduino IDE、PlatformIO 或串口调试工具。如果你不知道这些是什么，通常说明你没有打开它们，可以跳过这一步。

系统与驱动 macOS 无需手动安装驱动；Windows 10/11 联网时通常会自动安装。若设备管理器中出现两个 USB JTAG/serial debug unit，且“端口（COM 和 LPT）”下没有 USB 串行设备（COMx），说明驱动没有正确安装。 查看乐鑫官方驱动修复步骤 (https://docs.espressif.com/projects/esp-techpedia/zh_CN/latest/esp-friends/get-started/try-firmware/try-firmware-usb-driver.html)

DIY 项目 · 非医疗设备 Suger RGB 不应用于治疗决策，设备搭建与使用风险由用户承担。

光敏安全： 本设备可产生动态或闪烁灯光。光敏性癫痫、偏头痛患者或对闪光敏感者，请避免使用快速闪烁效果；如有不适，请立即停止使用。

GitHub (https://github.com/sid-luo/suger-rgb) 灯效演示 完整安装说明 (https://github.com/sid-luo/suger-rgb/blob/main/docs/INSTALL.md)

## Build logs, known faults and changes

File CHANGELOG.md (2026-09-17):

# Changelog

Suger RGB follows [Semantic Versioning](https://semver.org/). Dates use `YYYY-MM-DD`.

## [1.0.0] - 2026-09-17

Initial release:

- ESP32-C3 Pro Mini and 1–128 WS2812B pixels;
- five glucose color ranges with Nightscout trend effects;
- high-visibility effects below 3.3 mmol/L and at or above 15 mmol/L;
- ten-minute stale-data indication;
- bilingual captive setup page with connection validation and effect previews;
- BOOT long-press setup and connection reset;
- browser-based ESP32-C3 firmware installer;
- bilingual interactive browser demo for glucose colors, trends, and LED layouts;
- concise project overview plus separate Chinese and English step-by-step guides;
- setup HTTP server disabled during normal operation.

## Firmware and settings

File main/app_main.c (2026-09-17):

#include <stdbool.h>
#include <stdint.h>

#include "app_config.h"
#include "driver/gpio.h"
#include "esp_log.h"
#include "esp_system.h"
#include "esp_timer.h"
#include "freertos/FreeRTOS.h"
#include "freertos/task.h"
#include "led_controller.h"
#include "network_manager.h"
#include "nightscout.h"
#include "nvs_flash.h"
#include "portal.h"

#define BOOT_BUTTON_GPIO       GPIO_NUM_9
#define BOOT_HOLD_MS           5000
#define BUTTON_DEBOUNCE_MS     40
#define NIGHTSCOUT_POLL_MS     60000

static const char *TAG = "suger_rgb";
static app_config_t s_config;
static volatile bool s_config_mode;

static esp_err_t enter_config_mode(void)
{
    if (s_config_mode) {
        return ESP_OK;
    }

    s_config_mode = true;
    led_controller_show_config();
    esp_err_t err = network_manager_start_config_ap();
    if (err != ESP_OK) {
        ESP_LOGE(TAG, "Could not start configuration AP: %s", esp_err_to_name(err));
        s_config_mode = false;
        return err;
    }
    err = portal_start(&s_config);
    if (err != ESP_OK) {
        ESP_LOGE(TAG, "Could not start configuration page: %s", esp_err_to_name(err));
        s_config_mode = false;
        return err;
    }

    ESP_LOGI(TAG, "Configuration mode: connect to open network %s",
             network_manager_ap_ssid());
    return ESP_OK;
}

static void forced_restore_after_release(void)
{
    ESP_LOGW(TAG, "Forced restore requested; waiting for feedback animation");
    led_controller_wait_reset_feedback(6000);

    esp_err_t err = app_config_clear_connection();
    if (err != ESP_OK) {
        ESP_LOGE(TAG, "Could not clear connection settings: %s", esp_err_to_name(err));
    } else {
        ESP_LOGI(TAG, "Wi-Fi and Nightscout settings cleared; LED count preserved");
    }

    // GPIO9 is an ESP32-C3 strapping pin. Reboot only after the button has
    // actually been released, otherwise the chip can enter download mode.
    while (gpio_get_level(BOOT_BUTTON_GPIO) == 0) {
        vTaskDelay(pdMS_TO_TICKS(20));
    }
    vTaskDelay(pdMS_TO_TICKS(150));
    esp_restart();
}

static void boot_button_task(void *arg)
{
    (void)arg;
    bool last_raw_pressed = false;
    bool stable_pressed = false;
    bool hold_triggered = false;
    bool reset_armed = false;
    int64_t raw_changed_us = esp_timer_get_time();
    int64_t pressed_since_us = 0;

    while (true) {
        bool raw_pressed = gpio_get_level(BOOT_BUTTON_GPIO) == 0;
        int64_t now_us = esp_timer_get_time();

        if (raw_pressed != last_raw_pressed) {
            last_raw_pressed = raw_pressed;
            raw_changed_us = now_us;
        }

        if (raw_pressed != stable_pressed &&
            now_us - raw_changed_us >= BUTTON_DEBOUNCE_MS * 1000LL) {
            stable_pressed = raw_pressed;
            if (stable_pressed) {
                pressed_since_us = now_us;
                hold_triggered = false;
                reset_armed = false;
            } else {
                if (reset_armed) {
                    forced_restore_after_release();
                }
                // A complete release is mandatory before another long press
                // can be recognized. One continuous hold can never trigger
                // both configuration mode and forced restore.
                pressed_since_us = 0;
                hold_triggered = false;
                reset_armed = false;
            }
        }

        if (stable_pressed && !hold_triggered && pressed_since_us > 0 &&
            now_us - pressed_since_us >= BOOT_HOLD_MS * 1000LL) {
            hold_triggered = true;
            if (!s_config_mode) {
                ESP_LOGI(TAG, "BOOT long press: entering configuration mode");
                enter_config_mode();
            } else {
                ESP_LOGW(TAG, "BOOT long press in configuration mode: forced restore armed");
                reset_armed = true;
                led_controller_start_reset_feedback();
            }
        }

        vTaskDelay(pdMS_TO_TICKS(20));
    }
}

static void nightscout_poll_task(void *arg)
{
    (void)arg;
    bool have_reading = false;

    while (true) {
        if (!s_config_mode && network_manager_wait_connected(10000) == ESP_OK) {
            nightscout_reading_t reading;
            char error_message[160];
            esp_err_t err = nightscout_fetch_latest(s_config.nightscout_url, &reading,
                                                    error_message, sizeof(error_message));
            if (err == ESP_OK) {
                have_reading = true;
                led_controller_show_glucose(reading.glucose_mgdl, reading.timestamp_ms,
                                            reading.direction, reading.stale);
                ESP_LOGI(TAG, "Nightscout: %d mg/dL, direction=%s%s",
                         reading.glucose_mgdl, reading.direction,
                         reading.stale ? " (stale)" : "");
            } else {
                ESP_LOGW(TAG, "Nightscout update failed: %s", error_message);
                if (!have_reading) {
                    led_controller_show_no_data();
                }
            }
        } else if (!s_config_mode && !have_reading) {
            led_controller_show_no_data();
        }

        for (int elapsed = 0; elapsed < NIGHTSCOUT_POLL_MS / 250; ++elapsed) {
            vTaskDelay(pdMS_TO_TICKS(250));
            if (s_config_mode) {
                break;
            }
        }
    }
}

void app_main(void)
{
    esp_err_t nvs_err = nvs_flash_init();
    if (nvs_err == ESP_ERR_NVS_NO_FREE_PAGES || nvs_err == ESP_ERR_NVS_NEW_VERSION_FOUND) {
        ESP_ERROR_CHECK(nvs_flash_erase());
        nvs_err = nvs_flash_init();
    }
    ESP_ERROR_CHECK(nvs_err);
    ESP_ERROR_CHECK(app_config_load(&s_config));

    ESP_LOGI(TAG, "Starting Suger RGB; LED data GPIO=%d, count=%u",
             LED_DATA_GPIO, s_config.led_count);
    ESP_ERROR_CHECK(led_controller_init(s_config.led_count));
    led_controller_set_dynamic_trend(s_config.dynamic_trend_enabled);
    led_controller_show_no_data();
    ESP_ERROR_CHECK(network_manager_init());

    gpio_config_t button_config = {
        .pin_bit_mask = 1ULL << BOOT_BUTTON_GPIO,
        .mode = GPIO_MODE_INPUT,
        .pull_up_en = GPIO_PULLUP_ENABLE,
        .pull_down_en = GPIO_PULLDOWN_DISABLE,
        .intr_type = GPIO_INTR_DISABLE,
    };
    ESP_ERROR_CHECK(gpio_config(&button_config));
    xTaskCreate(boot_button_task, "boot_button", 3072, NULL, 6, NULL);

    if (s_config.complete) {
        ESP_LOGI(TAG, "Stored configuration found; connecting to Wi-Fi");
        ESP_ERROR_CHECK(network_manager_start_normal(&s_config));
        xTaskCreate(nightscout_poll_task, "nightscout_poll", 10240, NULL, 4, NULL);
    } else {
        ESP_LOGI(TAG, "No complete configuration found; starting pairing mode");
        s_config_mode = false;
        ESP_ERROR_CHECK(enter_config_mode());
    }
}

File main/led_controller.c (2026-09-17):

#include "led_controller.h"

#include <string.h>
#include <strings.h>

#include "app_config.h"
#include "driver/rmt_tx.h"
#include "esp_check.h"
#include "esp_log.h"
#include "esp_timer.h"
#include "freertos/FreeRTOS.h"
#include "freertos/semphr.h"
#include "freertos/task.h"

#define RMT_RESOLUTION_HZ        10000000
#define RMT_TX_TIMEOUT_MS        100
#define RMT_RECOVERY_DELAY_MS    10
#define DYNAMIC_REFRESH_MS       23
#define EFFECT_FRAME_MS          40
#define STALE_AFTER_US           (10LL * 60LL * 1000000LL)
#define RESET_PULSE_COUNT        3
#define RESET_PULSE_MS           1400
#define CONFIG_CHASE_WHITE       80
#define COLOR_EFFECT_FLOOR       5U
#define COLOR_EFFECT_PEAK        38U

// Approximate dynamic LED-current ceiling. A WS2812B color channel can draw
// about 20 mA at value 255. This is intentionally fixed and not user-facing.
// It leaves more USB-power headroom for the ESP32-C3 and Wi-Fi current peaks.
#define LED_OUTPUT_BUDGET_MA     250U
#define WS2812_CHANNEL_MA        20U
#define MAX_CHANNEL_BUDGET       (LED_OUTPUT_BUDGET_MA * 255U / WS2812_CHANNEL_MA)

typedef enum {
    DISPLAY_NO_DATA,
    DISPLAY_GLUCOSE,
    DISPLAY_CONFIG,
    DISPLAY_RESET_FEEDBACK,
} display_mode_t;

typedef struct {
    display_mode_t mode;
    uint16_t led_count;
    bool dynamic_trend_enabled;
    int glucose_mgdl;
    char direction[24];
    bool has_live_glucose;
    int64_t sample_timestamp_ms;
    int64_t sample_observed_us;
    bool sample_reported_stale;
    int64_t reset_started_us;

    // Development effect-lab override. These fields are RAM-only and are
    // deliberately absent from app_config/NVS.
    bool preview_active;
    led_effect_t preview_effect;
    int preview_glucose_mgdl;
    uint8_t preview_speed;
    bool preview_reverse;
} display_state_t;

typedef struct {
    uint8_t red;
    uint8_t green;
    uint8_t blue;
} rgb_t;

typedef struct {
    led_effect_t effect;
    uint8_t speed;
    bool reverse;
} effect_selection_t;

static const char *TAG = "led";
static uint8_t s_pixels[APP_MAX_LED_COUNT * 3];
static rgb_t s_color_twinkles[APP_MAX_LED_COUNT];
static uint64_t s_color_twinkles_fade_up;
static bool s_color_twinkles_initialized;
static uint32_t s_effect_rng = 0x5A17C3E9U;
static rmt_channel_handle_t s_led_channel;
static rmt_encoder_handle_t s_led_encoder;
static SemaphoreHandle_t s_reset_done;
static portMUX_TYPE s_state_lock = portMUX_INITIALIZER_UNLOCKED;
static display_state_t s_state = {
    .mode = DISPLAY_NO_DATA,
    .led_count = APP_DEFAULT_LED_COUNT,
    .dynamic_trend_enabled = true,
    .preview_effect = LED_EFFECT_SOLID,
    .preview_glucose_mgdl = 100,
    .preview_speed = 50,
    .direction = "Unknown",
};

static const rmt_symbol_word_t WS2812_ZERO = {
    .level0 = 1,
    .duration0 = 3,
    .level1 = 0,
    .duration1 = 9,
};

static const rmt_symbol_word_t WS2812_ONE = {
    .level0 = 1,
    .duration0 = 9,
    .level1 = 0,
    .duration1 = 3,
};

static const rmt_symbol_word_t WS2812_RESET = {
    .level0 = 0,
    .duration0 = 250,
    .level1 = 0,
    .duration1 = 250,
};

static size_t ws2812_encoder_callback(const void *data, size_t data_size,
                                      size_t symbols_written, size_t symbols_free,
                                      rmt_symbol_word_t *symbols, bool *done, void *arg)
{
    (void)arg;
    if (symbols_free < 8) {
        return 0;
    }

    size_t data_pos = symbols_written / 8;
    const uint8_t *bytes = data;
    if (data_pos < data_size) {
        size_t symbol_pos = 0;
        for (uint8_t mask = 0x80; mask != 0; mask >>= 1) {
            symbols[symbol_pos++] = (bytes[data_pos] & mask) ? WS2812_ONE : WS2812_ZERO;
        }
        return symbol_pos;
    }

    symbols[0] = WS2812_RESET;
    *done = true;
    return 1;
}

static void set_pixel(uint16_t index, rgb_t color, uint8_t scale)
{
    if (index >= APP_MAX_LED_COUNT) {
        return;
    }
    // WS2812B byte order is GRB.
    s_pixels[index * 3 + 0] = (uint16_t)color.green * scale / 255;
    s_pixels[index * 3 + 1] = (uint16_t)color.red * scale / 255;
    s_pixels[index * 3 + 2] = (uint16_t)color.blue * scale / 255;
}

static uint8_t saturating_add8(uint8_t left, uint8_t right)
{
    uint16_t sum = (uint16_t)left + right;
    return sum > 255U ? 255U : (uint8_t)sum;
}

static uint8_t scale8_video(uint8_t value, uint8_t scale)
{
    if (value == 0 || scale == 0) {
        return 0;
    }
    return ((uint16_t)value * scale >> 8) + 1U;
}

static uint32_t effect_random32(void)
{
    // Small deterministic xorshift generator. The LED task is its only caller.
    uint32_t value = s_effect_rng;
    value ^= value << 13;
    value ^= value >> 17;
    value ^= value << 5;
    s_effect_rng = value;
    return value;
}

static uint8_t effect_random8(void)
{
    return (uint8_t)(effect_random32() >> 24);
}

static uint16_t effect_random_pixel(uint16_t led_count)
{
    return ((uint64_t)effect_random32() * led_count) >> 32;
}

static rgb_t rainbow_wheel(uint8_t position)
{
    position = 255U - position;
    if (position < 85U) {
        return (rgb_t){
            .red = 255U - position * 3U,
            .green = 0,
            .blue = position * 3U,
        };
    }
    if (position < 170U) {
        position -= 85U;
        return (rgb_t){
            .red = 0,
            .green = position * 3U,
            .blue = 255U - position * 3U,
        };
    }
    position -= 170U;
    return (rgb_t){
        .red = position * 3U,
        .green = 255U - position * 3U,
        .blue = 0,
    };
}

static void apply_fixed_power_budget(uint16_t led_count)
{
    uint32_t sum = 0;
    const size_t byte_count = (size_t)led_count * 3;
    for (size_t i = 0; i < byte_count; ++i) {
        sum += s_pixels[i];
    }
    if (sum <= MAX_CHANNEL_BUDGET || sum == 0) {
        return;
    }

    for (size_t i = 0; i < byte_count; ++i) {
        s_pixels[i] = (uint32_t)s_pixels[i] * MAX_CHANNEL_BUDGET / sum;
    }
}

static esp_err_t transmit_pixels_once(uint16_t led_count)
{
    rmt_transmit_config_t tx_config = {.loop_count = 0};
    esp_err_t err = rmt_transmit(s_led_channel, s_led_encoder, s_pixels,
                                 (size_t)led_count * 3, &tx_config);
    if (err == ESP_OK) {
        err = rmt_tx_wait_all_done(s_led_channel, RMT_TX_TIMEOUT_MS);
    }
    return err;
}

static esp_err_t recover_led_channel(void)
{
    esp_err_t err = rmt_disable(s_led_channel);
    if (err != ESP_OK) {
        return err;
    }

    // rmt_disable() terminates and recycles an interrupted transaction. Flush
    // its completed descriptor before enabling the channel again.
    err = rmt_tx_wait_all_done(s_led_channel, 0);
    if (err != ESP_OK) {
        return err;
    }
    vTaskDelay(pdMS_TO_TICKS(RMT_RECOVERY_DELAY_MS));
    return rmt_enable(s_led_channel);
}
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
